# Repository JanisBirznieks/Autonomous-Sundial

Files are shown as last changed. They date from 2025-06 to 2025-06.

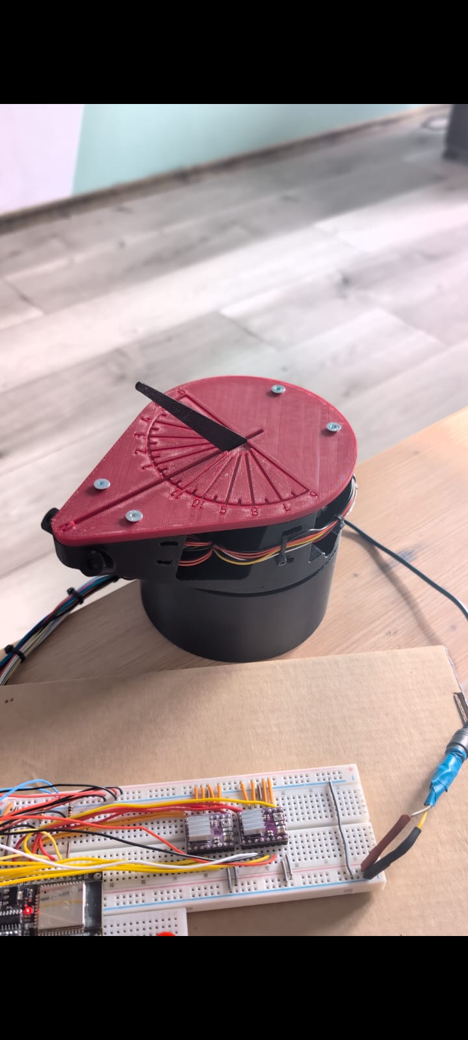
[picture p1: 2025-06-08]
Sundial.jpeg

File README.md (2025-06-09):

#  Autonomous Sundial

**Author:** Jānis Birznieks  
**Year:** 2025

This project is a physical, electromechanical sundial system that autonomously tracks the sun’s position to display accurate local solar time. It combines mechanical actuation, environmental sensing, and real-time data integration across three cooperating devices.

---

## 🔧 System Overview

The system runs across three hardware platforms, each with its own software component:

### 1. **ESP32 (Firmware: `main.cpp`)**
- Controls two stepper motors (azimuth + tilt)
- Reads sensor data (LDRs, AS5600 analog angle sensors, limit switches)
- Implements the full state machine (OFF, ON, PAUSED, RESET)  
- Executes sun-seeking and initialization subroutines

### 2. **Raspberry Pi (Script: `ESPSerialSender.py`)**
- Sends current time and location to the ESP32
- Reads serial telemetry from the ESP32
- Stores all received data in a local MySQL database

### 3. **Database/Visualization Machine (Script: `Sundial_Plots.py`)**
- Connects to the MySQL database
- Displays:
  - Polar chart for real-time azimuth
  - Polar chart for gnomon tilt
  - Smoothed time-series plots of LDR data
  - Live system state indicator

---

## 🧩 Included Components

| Type | File | Description |
|---|---|---|
| ESP32 Code  | `main.cpp` | Core firmware controlling motors, state logic, and sensors |
| Pi Script | `ESPSerialSender.py` | Syncs time/location and logs telemetry |
| Visualizer  | `Sundial_Plots.py` | Live data visualization from the MySQL database |

---

## 📄 License

This repository is distributed under a **custom Academic Use License**.

You are permitted to use, study, and modify this work **for non-commercial academic or research purposes only**. Commercial use is **strictly prohibited** without written permission from the author.

See [`LICENSE.txt`](LICENSE.txt) for full terms.

---

## 🛠️ Status

This is an academic project submitted as part of a final coursework requirement. The repository is currently **private** and shared for review purposes only.

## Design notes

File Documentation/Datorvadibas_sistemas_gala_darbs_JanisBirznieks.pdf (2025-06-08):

### RĪGAS TEHNISKĀ UNIVERSITĀTE

## Liepājas akadēmija

## Jānis Birznieks

## Mehatronika 3.kurss

## 191LMC006

# Autonomais saules pulkstenis

Students

Darba vadītājs

## Liepāja 2025

### Saturs

## Ievads

Saules pulksteņi ir vieni no senākajiem laika noteikšanas instrumentiem, kas darbojas, izmantojot Saules pozīciju un ēnas krišanas virzienu, lai norādītu aptuvenu diennakts laiku. Lai tie pareizi darbotos, saules pulkstenim jābūt orientētam pret īstajiem ziemeļiem, jo tieši no šīs puses tiek veikti ģeogrāfiskie novērojumi. Turklāt gnomona — ēnas metēja — leņķim jāatbilst lietotāja ģeogrāfiskajai platuma grādu vērtībai, lai ēna precīzi rādītu laiku.

Mūsdienās, kad pulksteņi un viedierīces ir plaši pieejamas un ļoti precīzas, saules pulksteņi vairāk tiek izmantoti kā dekoratīvi vai izglītojoši objekti. Tomēr šo klasisko laika noteikšanas principu var apvienot ar mūsdienu tehnoloģijām, radot automatizētu saules pulksteni, kas spēj patstāvīgi noteikt savu orientāciju un pielāgoties lietotāja atrašanās vietai.

Šī projekta mērķis ir izstrādāt ierīci, kura, izmantojot mikrodatoru un sensorus, automātiski noregulē savu pozīciju un gnomona leņķi, nodrošinot precīzu un ērtu laika nolasīšanu no saules pulksteņa neatkarīgi no tā, kur ierīce tiek novietota.

Projekts apvieno vairākas tehnoloģiskās jomas — mehānisko konstrukciju, sensoru datu apstrādi, mikrokontrolieru un mikrodatoru komunikāciju, kā arī algoritmu izstrādi. Lai gan šīs ierīces praktiskā nozīme mūsdienās ir ierobežota, projekts sniedz vērtīgu pieredzi inženiertehniskajā risinājumā, apgūstot sensoru integrāciju un automatizētu kontroli.

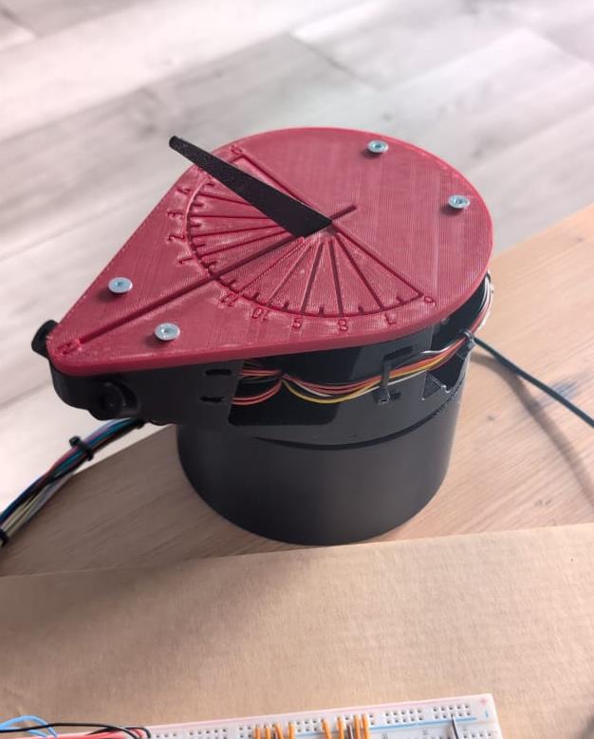
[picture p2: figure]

Attēls 1, Autonomā saules pulksteņa elektromehāniskais izpildījums

## Tēmas pamatojums

Šī projekta izvēle balstās uz vēlmi apvienot klasisku, analogā laikmeta tehnoloģiju – saules pulksteni – ar mūsdienu digitālajām iespējām, demonstrējot, kā tradicionālus mehānismus iespējams modernizēt ar mikroelektroniku, automatizāciju un sensoriem. Lai arī izveidotā ierīce būtībā atkārto funkciju, kuru mūsdienās veic jebkurš viedtālrunis vai pulkstenis, šī “tehnoloģiski pārsarežģītā” pieeja ļauj padziļināti izprast:

- analogā un digitālā signālu apstrādi;
- dažādu sensoru un aktuatoru pielietošanu;
- ģeogrāfisko koordinātu izmantošanu aprēķinos;
- mikrokontrolleru un mikrodatoru sadarbību;
- automatizētu mehānismu vadības algoritmu izstrādi.

Tēmas izvēle arī parāda, kā ar šķietami vienkāršu un “nepraktisku” ideju iespējams radīt daudzslāņainu projektu, kurā nepieciešama nopietna tehniskā plānošana un īstenošana. Šāda pieeja ne tikai ļauj demonstrēt dažādu jomu prasmes, bet arī motivē radošu pieeju inženiertehnisku risinājumu meklējumos.

## Prasību specifikācija

Funkcionālās prasības:

- Sistēmas ieejas (nolasāmie parametri):
- Lietotāja atrašanās vieta (platums un garums) – automātiski nolasīta (caur RasPi).
- Laiks – iegūts no Raspberry Pi (interneta sinhronizācija).
- Gaismas sensori – nosaka, no kurienes nāk spēcīgākais apgaismojums (analoga ievade).
- Enkoderi uz soļu motoriem – precīzai pozīcijas kontrolei un kļūdu korekcijai (ja gnomons vai pulkstenis kustības laikā tiek bloķēts).
- Divas pogas – ierīces ieslēgšana/izslēgšana, pauze vai attiestatīšana
- Aktuatora darbības atkarība no ievades:
- Soļu motori rotē platformu, lai to orientētu pret sauli, un pielāgo gnomona leņķi atkarībā no platuma.
- Sistēma automātiski aprēķina saules azimutu no laika un koordinātēm.
- Pozicionēšana tiek veikta, balstoties uz aprēķināto saules pozīciju, ar atsauci no enkoderiem.
- Datu apstrāde / pārsūtīšana / vizualizācija:
- ESP32 saņem datus no Raspberry Pi (laiks, atrašanās vieta).
- LED indikatori:
- Zaļais – sistēma ir iestatījusies.
- Dzeltenais - notiek sistēmas darbība,
- Sarkanais – sistēma izslēgta.
- ESP32 pārsūta aziumta leņķi, gaismas sensoru vērtības, platuma leņķi, sistēmas stāvokli uz Raspberry Pi, kas to tālāk nosūta uz lokālo datubāzi.
- Datubāzes iekārta veic datu vizualizāciju un apstrādi.
- Lietotāja saskarne:
- 2 pogas.
- 2 LED (zaļš un sarkans).

## Moduļu slēgums (komponentes)

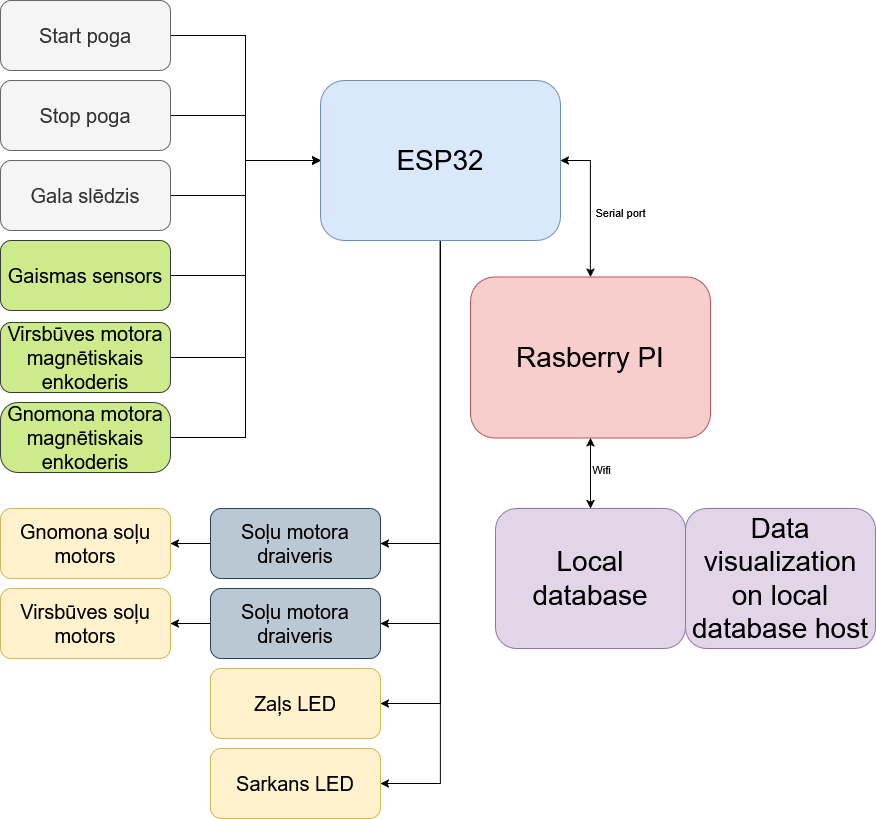
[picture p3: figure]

Attēls 2, Moduļu slēgums

Moduļu slēguma apraksts

Šajā sistēmā izmantota modulāra pieeja, kurā mikrokontrolleris ESP32 pārvalda sensorus, pogas, motorus un indikatorus, bet Raspberry Pi mikrodators reģistrē lokāciju un laika datus, kā arī pārsūta informāciju uz datubāzi.

ESP32 mezgls

ESP32 kalpo kā centrālais kontrolieris, kurš veic:

- Signālu nolasīšanu no ieejām:
- Start poga – aktivizē sistēmas ciklu.

- Stop poga – iedarbina pauzes vai izslēgšanas režīmu.
- Gala slēdzis – kalpo kā gnomona references punkts.
- Gaismas sensori (LDR) – noteic Saules virzienu.
- Magnetiskie enkoderi – reģistrē bāzes un gnomona motora pozīciju, izmantojot analogās vērtības no AS5600 sensoriem.
- Signālu nosūtīšanu uz izejām:
- Soļu motora draiveri – vadības signāli tiek sūtīti uz bāzes un gnomona motoriem (DRV8825), lai izpildītu kustības uz noteiktiem leņķiem.
- LED indikatori:

■ Zaļais LED - sistēma ir pabeigusi darbību.
■ Dzletenais LED - sistēma ir darbībā vai pauzē. ■ Sarkanais LED - sistēma ir izslēgta.

ESP32 arī veic aprēķinus, piemēram, pozicionēšanos pēc gaismas sensoriem un gnomona leņķa iestatīšanu pēc lietotāja koordinātām un laika.

Raspberry Pi mezgls

Raspberry Pi saņem seriālos datus no ESP32 caur serial port. Tas darbojas kā starpnieks starp ierīci un vietējo MySQL datubāzi – glabā datus par laiku, atrašanās vietu, Saules azimutu, sensoru mērījumiem, sistēmas stāvokli u.c. Datubāzes ierīcē notiek arī datu vizualizācijas – reāllaikā attēlo:

- Saules azimuta un gnomona leņķa polārās diagrammas,
- LDR vērtību vēsturi,
- sistēmas stāvokļa indikatoru.

## Principiālā shēma

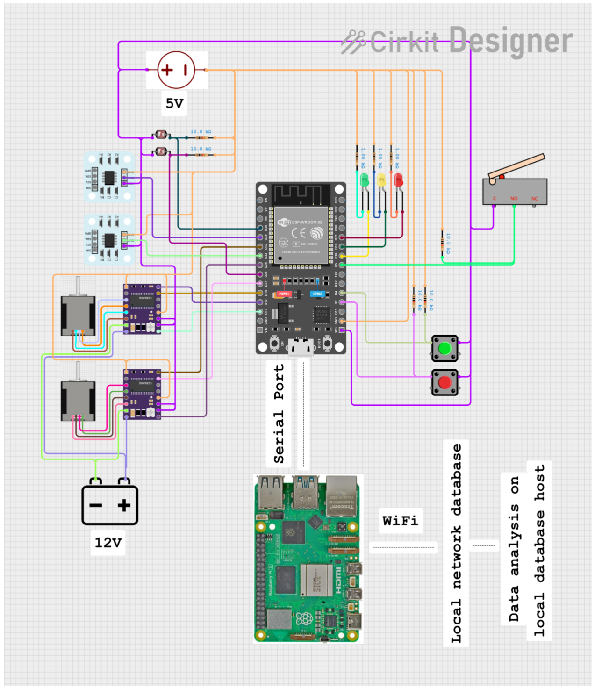
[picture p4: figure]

Attēls 3, Principiālā shēma

Komponente | Pins | Savienots ar
NEMA 17 | GREEN (A1) | DRV8825 A1
| BLUE (A2) | DRV8825 A2
| BLACK (B1) | DRV8825 B1
| RED (B2) | DRV8825 B2
NEMA 14 | RED (B2) | DRV8825 B2
| BLACK (B1) | DRV8825 B1
| GREEN (A1) | DRV8825 A1
| BLUE (A2) | DRV8825 A2
12V barošana | | DRV8825 VMOT, VMOT, GND
ESP32 | D14 | DRV8825 STEP
| D12 | DRV8825 DIR
| D13 | DRV8825 EN
| D27 | DRV8825 STEP
| D32 | DRV8825 DIR
| D25 | DRV8825 EN
Photocell (LDR1) | Pin 1 | Resistor, ESP32 D34
Photocell (LDR2) | Pin 1 | ESP32 D26
Galaslēdzis | NO | ESP32 D5
Pushbutton | Pin 1 | ESP32 D2
Pushbutton | Pin 1 | ESP32 D4
LED (green) | Anode | ESP32 D18
LED (yellow) | Anode | ESP32 D19
LED (red) | Anode | ESP32 D21
Tabula 1, Slēguma tabula

## Algoritms

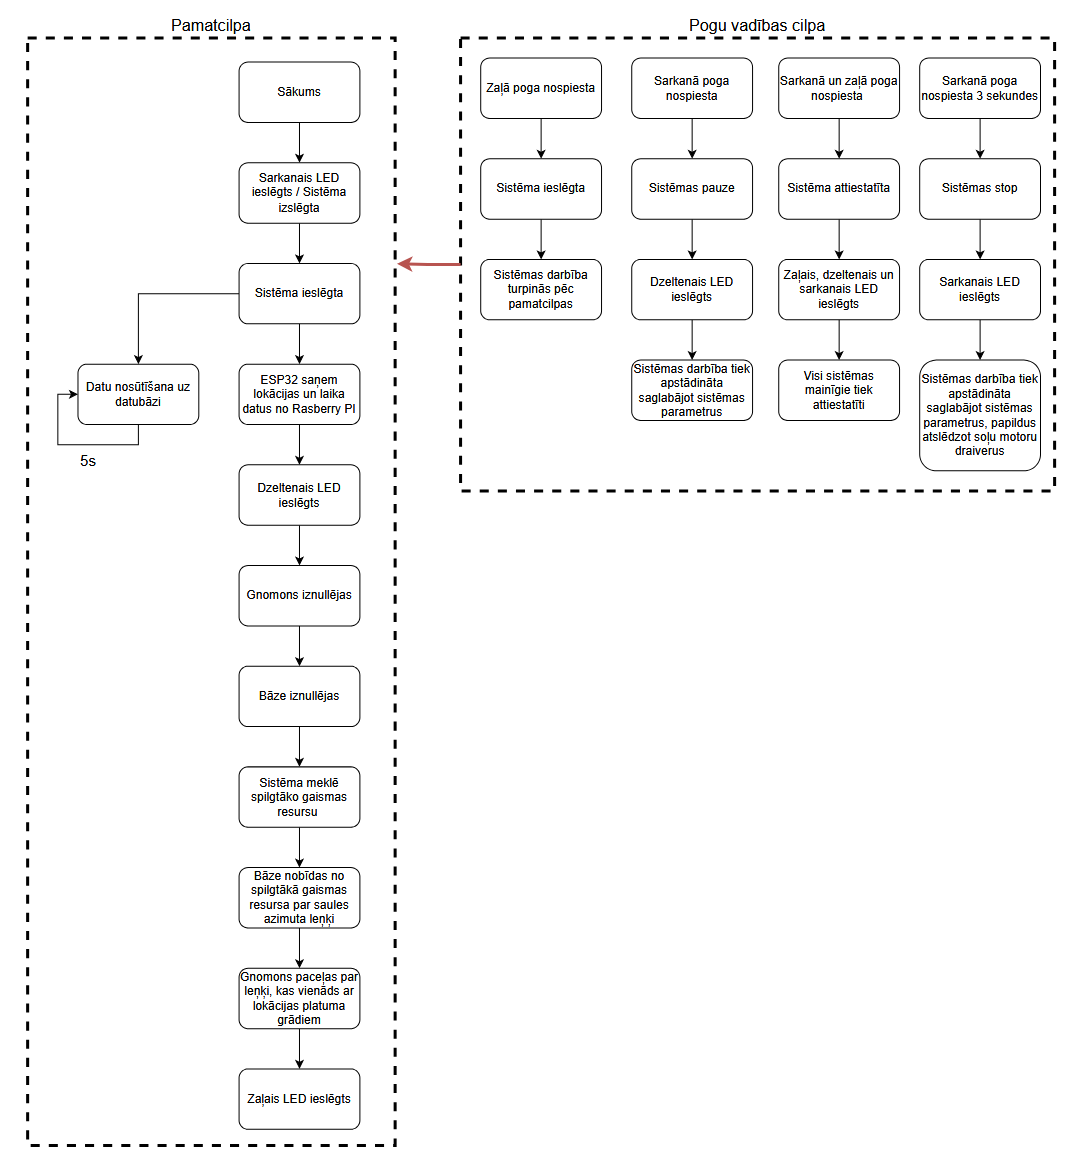
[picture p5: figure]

Attēls 4, Programmas algoritma blokshēma

## Galvenā cikla darbība

## Sistēmai pirmoreiz uzsākot darbu, tiek ieslēgts sarkans indikators, norādot, ka sistēma

ir izslēgta vai gaidstāvē. Kad lietotājs to ieslēdz, iedegas dzeltens LED, un sākas sistēmas

## darbības process . Vispirms ESP32 saņem reālā laika informāciju un atrašanās vietu no

Raspberry Pi (kas to attiecīgi ir saņēmis no interneta), un no šiem datiem aprēķina Saules azimuta leņķi.Tālāk gan bāze, gan gnomons tiek atgriezti sākuma pozīcijā.

## Kad tas paveikts, sistēma izmanto LDR (gaismas sensorus), lai atrastu spilgtāko gaismas avotu. Pēc tam, pamatojoties uz šo informāciju:

- Bāze tiek novirzīta par saules azimuta leņķi no spilgtākā gaismas avota.
- Gnomons paceļas atbilstoši lokācijas platuma grādiem.

## Sistēma aktivizē zaļo LED, kas norāda uz normālu darbību.Visu darbības laiku,ik pēc 5 sekundēm sistēma nosūta datus uz MySQL datubāzi, tai skaitā:

- laiku,
- aprēķināto Saules azimutu,
- LDR sensoru rādījumus,
- lokācijas platuma leņķi,
- sistēmas stāvokli.

## Pogu vadības apakšcikls

## Šis cikls darbojas neatkarīgi no galvenā cikla un ļauj lietotājam jebkurā brīdī mainīt sistēmas stāvokli:

- Sarkanā poga aktivizē pauzes režīmu, apstādinot motorus. Iedegas dzeltens LED.
- Zaļā poga atsāk darbību pēc pauzes.

## - Sarkanā + zaļā poga kopā izraisa atiestatīšanu – visi mainīgie tiek atgriezti sākotnējā

stāvoklī.

## - Sarkanā poga, turot to nospiestu 3 sekundes, izslēdz sistēmu, deaktivizē motoru

draiverus – aktivizējas sarkanais LED.

## Kods (apraksts)

Programmatūras sistēma ir paredzēta, lai fizikāli izkārtotu saules pulksteni atbilstoši saules pašreizējai pozīcijai, izmantojot reāllaika atrašanās vietas un laika datus. Sistēma sastāv no trim savstarpēji savienotām ierīcēm, kurās katrā darbojas specifiska programma:

- ESP32 — Autonomous Sundial (main.cpp): Vada aktuatorus, nolasa sensorus un izpilda visu saules pulksteņa mehānisko kustību.
- Raspberry Pi — ESPSerialSender.py : Iegūst ģeolokāciju un laiku no interneta, sazinās ar ESP32 un pārsūta sistēmas datus uz datubāzi.
- Datu bāzes ierīce — Sundial_Plots.py : Iegūst datus no MySQL datubāzes un vizualizē sistēmas statusu, sensoru rādījumus un saules orientāciju reāllaikā.

ESP32 — Autonomous Sundial (main.cpp)

Programmas mērķis

Šī programma darbojas uz ESP32 un veido sistēmas galveno vadības loģiku. Tās uzdevumi ir:

- Vadīt bāzes un gnomona motorus, izmantojot soļu motoru draiverus un analogo sensoru atgriezenisko saiti.
- Saņemt laiku un atrašanās vietas datus no Raspberry Pi.
- Aprēķināt saules pozīciju ar saules pozicionēšanas bibliotēku.
- Izmantot gaismas sensorus (LDR), lai nomērītu saules atrašanās pozīciju.
- Apstrādāt lietotāja ievadi caur pogām un norādīt sistēmas stāvokli ar LED indikatoriem.
- Nosūtīt sistēmas statusu un datus atpakaļ uz Raspberry Pi caur seriālo savienojumu.

Programma organizēta kā state machine, kas pārvalda sistēmas darbību (OFF, ON, PAUSED, RESET), un sub-state machine, kas veic saules pulksteņa uzstādīšanas un pozicionēšanas procedūru.

Galvenās apakšprogrammas un funkcijas

Zemāk aprakstīti katras funkcijas uzdevumi:

## 1. void resetMotorStates()

Atiestata visu motoru stāvokļu mainīgos. Izsaucas pēc sistēmas restartēšanas, lai motori sāktu no nulles pozīcijas.

## 2. bool trackLightSource(...)

LDR balstīta gaismas avota izsekošana:

- Salīdzina kreisās un labās LDR sensoru vērtības.
- Groza bāzes motoru, līdz sensori ir līdzsvaroti tolerances robežās.
- Ņem vērā spilgtāko gaismas avotu
Šis posms palīdz noteikt saules aptuveno pozīciju.

## 3. bool rotateMotorByOffset(...)

Groza motoru par relatīvu leņķi (piemēram, saules azimuta nobīdi):

- Nolasa pašreizējo pozīciju no AS5600 sensora.
- Aprēķina mērķa pozīciju kā: pašreizējā + nobīde.
- Kustība turpinās, līdz tiek sasniegta mērķpozīcija.

## 4. bool rotateMotorToPosition(...)

Groza motoru uz konkrētu absolūtu pozīciju:

- Līdzīga kā rotateMotorByOffset, bet ar fiksētu mērķi (piemēram, sākuma pozīciju).
- Lieto bāzes vai gnomona "nulēšanai".

## 5. void checkButtons()

Apstrādā pogu ievades, izmantojot Bounce2 bibliotēku:

- Zaļā + sarkanā poga → sistēmas RESET
- Zaļā poga → sistēma ON
- Sarkanā poga → sistēma PAUSED
- Sarkanās pogas turēšana 3 sekundes → sistēma OFF

## 6. void calculateSunAzimuth()

Aprēķina saules pašreizējo azimutu, izmantojot laiku un atrašanās vietu:

- Izmanto saules pozīciju bibliotēku.
- Leņķis pārveidots motoru mērogā (0–4096).

## 7. void parseSerialCommand(const String& input)

Apstrādā ienākošās seriālās komandas, kas atjauno sistēmas iekšējos mainīgos laika un vietas datiem.:

## - TIME:<hh>,<mm>,<ss>,<dd>,<mm>,<yyyy> - LOC:<platums>,<garums>

## 8. void receiveSerialData()

Nolasa seriālo buferi un nodo ievadītos datus parseSerialCommand funkcijai. Nodrošina, ka

ESP32 spēj saņemt Raspberry Pi sūtītos datus.

## 9. void sendSystemData()

Nosūta telemetrijas datus atpakaļ uz Raspberry Pi:

- Iekļauj: laika zīmogu, platumu, garumu, saules azimutu, LDR vērtības, bāzes leņķi, sistēmas stāvokli.

- Dati formatēti kā teksta rinda ar DATA: prefiksu.

Sistēmas inicializācija un galvenais cikls

## void setup()

Inicializē:

- Seriālo savienojumu
- Motora "enable" pinus
- Pogas un LED pinus
- Pogu atskaites laiku (debounce)
- Sākas SYSTEM_OFF stāvoklī.

## void loop()

Galvenā programma strukturēta ap stāvokļu mašīnu:

Sistēmas stāvokļi

1. SYSTEM_OFF
- Motori atspējoti.
- Iedegas sarkanais LED.
- Sistēma gaida.
2. SYSTEM_ON
Aktivizē apakšstāvokļu secību, lai sagatavotu un pozicionētu saules pulksteni: Apakšstāvokļi:
- STEP_ZERO_GNOMON: Gnomons tiek rotēts līdz mehāniskajai nulles pozīcijai

(izmantojot gala slēdzi).
- STEP_ZERO_BASE: Bāze tiek noregulēta uz fiksētu sākuma pozīciju (izmantojot

sensoru).
- SUN_TRACKING: Bāze tiek virzīta uz spožāko gaismas avotu (izmantojot LDR

sensorus).
- STEP_ROTATE_BASE: Bāze tiek rotēta atbilstoši saules azimuta aprēķinam.
- STEP_ROTATE_GNOMON: Gnomons tiek pacelts līdz vietējam platuma leņķim.
- STEP_DONE: Visi soļi pabeigti. Zaļais LED iedegas. Sistēma ir noregulēta.
3. SYSTEM_PAUSED
- Motori apstājas.
- Dzeltens LED iedegas.
4. SYSTEM_RESET
- Atiliek sistēmu uz sākuma stāvokli.
- Gaidīt laika un vietas datus.

Seriālā izvade

Cikla beigās ik pēc 5 sekundēm tiek izsaukta sendSystemData() funkcija, kas nosūta

aktuālos datus uz Raspberry Pi.

## Raspberry Pi — ESPSerialSender.py

Programmas mērķis

Šī Python programma darbojas uz Raspberry Pi un kalpo kā saziņas un datu apmaiņas tilts starp ESP32 un datubāzes serveri. Tās uzdevumi ir:

- Iegūt reāllaika laiku un atrašanās vietas datus no interneta, izmantojot iebūvēto sistēmas pulksteni un geocoder bibliotēku.
- Nosūtīt šo informāciju ESP32, lai tas spētu aprēķināt saules pozīciju.
- Saņemt sistēmas datus no ESP32 seriālajā formātā un saglabāt tos MySQL datubāzē.

Programma darbojas nepārtrauktā ciklā, regulāri atjauninot informāciju un uzraugot ESP32 izsūtītos datus.

Galvenās funkcijas

## send_time_and_location()

- Iegūst lokālo laiku.
- Mēģina noteikt ģeogrāfiskās koordinātas (platumu un garumu) ar IP balstītu geolokāciju.
- Ja tas neizdodas, izmanto rezerves vērtības.
- Nosūta datus uz ESP32 divās atsevišķās komandās: TIME: un LOC:.

## read_esp_data()

- Klausās seriālajā portā.
- Ja saņemta rinda, kas sākas ar DATA:, tā tiek parsēta 8 laukos:
- Laika zīmogs
- Platums
- Garums
- Saules azimuts
- LDR kreisais sensors
- LDR labais sensors
- Bāzes pozīcija
- Sistēmas stāvoklis
- Pēc veiksmīgas parsēšanas dati tiek ierakstīti MySQL datubāzē ar
insert_data_to_mysql(...).

## insert_data_to_mysql(...)

- Veic SQL INSERT vaicājumu tabulā sun_tracking_data, saglabājot visu ienākošo

telemetriju strukturētā veidā.

Galvenais cikls

Programma darbojas bezgalīgā while True ciklā:

- Ik pēc 5 sekundēm tiek izsaukta send_time_and_location(), lai nodrošinātu ESP32

ar aktuāliem datiem.
- Nepārtraukti tiek klausīts ESP32 seriālais izvads, un saņemtie dati tiek apstrādāti.
- Starp cikliem programma īslaicīgi "guļ", lai mazinātu CPU noslodzi (sleep(0.9)).

Kopsavilkums

Šī programma ir vienkārša, bet būtiska — tā sinhronizē ESP32 ar reālo pasauli (laiku un atrašanās vietu) un nodrošina telemetrijas plūsmu uz datubāzi.

Datu bāzes ierīce — Sundial_Plots.py

Programmas mērķis

Šī Python programma darbojas uz vietējās datubāzes ierīces un nodrošina reāllaika vizualizāciju par saules pulksteņa sistēmas darbību. Tās uzdevumi ir:

- Savienoties ar MySQL datubāzi un nolasīt jaunākos telemetrijas ierakstus.
- Attēlot datus vizuāli, izmantojot matplotlib, sniedzot lietotājam skaidru priekšstatu par

sistēmas stāvokli, saules pozīciju, sensoru rādījumiem u.c.
- Atjaunot grafikus ik pēc 5 sekundēm

Vizualizācijas paneļi

Programma izveido četrus galvenos skatījumus (subplot) vienā logā:

### 1. Saules azimuts (polārais grafiks)

- Attēlo saules virzienu uz kompasa diska.
- 0° = Ziemeļi; grafiks orientēts ar pulksteņrādītāja virzienu.
- Dati tiek iegūti no pēdējā sun_azimuth ieraksta datubāzē.

### 2. Gnomona slīpums (polārais grafiks)

- Attēlo platuma leņķi lietotāja lokācijā.

### 3. LDR sensoru vērtības (līniju grafiks)

- Attēlo kreisā un labā LDR sensora vērtības laika gaitā.
- Dati tiek izlīdzināti ar vienkāršu delta koeficientu (SMOOTHING_DELTA), lai iegūtu

gludāku līkni.
- Rāda līdz 100 pēdējiem punktiem (MAX_POINTS).

### 4. Sistēmas stāvoklis (teksta logs)

- Vizualizē, kādā stāvoklī šobrīd atrodas sistēma (piemēram, SYSTEM_ON, SYSTEM_PAUSED,

utt.).
- Teksts centrēts, ar palielinātu fontu ērtai nolasīšanai.

Datu iegūšana

## fetch_latest_data()

- Veic SQL pieprasījumu uz sun_tracking_data tabulu.
- Iegūst jaunākos ierakstus (pēc timestamp), apgriež to kārtību hronoloģiskai attēlošanai.
- Atgriež rezultātus kā sarakstu ar vārdotiem lauciņiem (dictionary=True).

Grafiku atjaunošana

## update_plot(frame)

- Tiek izsaukta ik sekundi, izmantojot matplotlib.animation.FuncAnimation.
- Atjauno visus četrus vizualizācijas paneļus ar jaunākajiem datiem no datubāzes.
- Veic LDR datu izlīdzināšanu, pārkonvertē leņķus uz radiāniem polārajiem grafikiem.

Kopsavilkums

Sundial_Plots.py ir lietotāja interfeiss sistēmas uzraudzībai. Tas piedāvā vizuālu un intuitīvu skatījumu uz sensoriem, mehānismiem un saules pozīciju, un ļauj nekavējoties redzēt, kā sistēma reaģē uz vidi un ievaddatiem.

Koda pielikumu saraksts:

- Pielikums A – main.pdf (css)
ESP32 mikrokontrollera programma: Autonomous Sundial
- Pielikums B – ESPSerialSender.pdf (py)
Raspberry Pi skripts: laika/atrašanās vietas sinhronizācija un datu uzglabāšana
- Pielikums C – Sundial_Plots.pdf (py)
Vizualizācijas rīks, kas lasa no MySQL datubāzes un attēlo datus reāllaikā

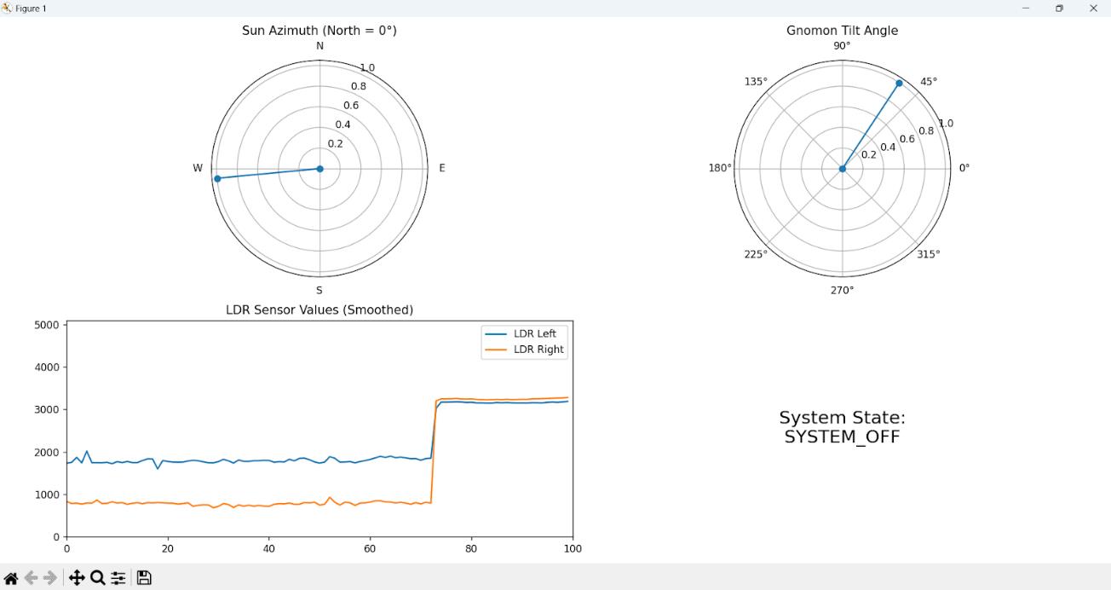
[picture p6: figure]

Attēls 5, Vizualizācija Sundial_plots.py

## Testēšana

Nr. | Testēšanas elements | Testēšanas mērķis | Rezultāts
1 | Sistēmas barošana | Pārbaudīt, vai ESP32 un visi komponenti saņem atbilstošu barošanu | Sistēma ieslēdzas pareizi un LED indikatori darbojas
2 | Stepper draivera strāvas iestatījums | Optimizēt motora strāvu, lai novērstu pārkaršanu vai zemu griezes momentu | Iestatīts uz 0.3 V ref, motors darbojas stabili
3 | Pogas (Start, Stop, Reset, Emergency) | Pārbaudīt pogu darbību un sistēmas reakciju uz tām | Sistēma korekti pārslēdz stāvokļus, Emergency aptur visu darbību
4 | Limit switch | Pārbaudīt nulles pozīcijas noteikšanu un aizsardzību | Limit switch nostrādā un sistēma korekti nolasa pozīciju
5 | Gnomona motors | Pārbaudīt motora darbību un virziena kontroli | Motors kustas pareizi un tiek kontrolēts caur stepper draiveri
6 | Bāzes motors | Pārbaudīt rotācijas kustību un pozicionēšanu | Motors rotē 360°, tiek veikta korekta pozicionēšana
7 | AS5600 sensori | Pārbaudīt sensora datus un to reakciju uz kustību | Abi sensori strādā bez problēmām
8 | LDR sensori | Pārbaudīt saules gaismas intensitātes nolasīšanu un reakciju uz to | Viens LDR bojāts — nomainīts; pēc tam abi darbojas korekti
9 | Gaismas izsekošanas algoritms | Pārbaudīt, vai tiek izsekots pareizais gaismas avots | Sākotnēji izsekoja nepareizus avotus; tika ieviests algoritms ar spilgtuma pārbaudi un ilguma filtru
10 | Motora vadības algoritmu testēšana | Pārbaudīt, vai kustības tiek pareizi aprēķinātas un veiktas (stepper vadība, leņķu kompensācija, nulles pozīcija) | Motori kustas paredzētajā virzienā un ātrumā, tiek ievērota tolerances zona un tiek veikta korekta pozicionēšana
11 | Datu nosūtīšana uz Raspberry Pi | Pārbaudīt, vai ESP32 pareizi nosūta telemetrijas datus uz RPi | Seriālā komunikācija strādā, dati tiek nosūtīti ik sekundi
12 | SQL datubāze | Pārbaudīt, vai dati tiek ierakstīti datubāzē | Veiksmīgi tiek glabāti dati par pozīcijām, gaismas intensitāti, sistēmas statusu
13 | Datu vizualizācija Python | Reālā laikā attēlot azimutu, lokācijas platuma leņķi, LDR vērtības un sistēmas statusu | Grafiki tiek atjaunoti ik sekundi, rādījumi ir vizuāli korekti
14 | Gaismas avota simulācija ar datora ekrānu | Sākotnējā testēšana bez RS-35 luktura | Sistēma reaģēja uz ekrāna gaismu, bet netika sasniegta pietiekama spilgtuma uzticamība
15 | Mehāniskā bāzes savienojuma izturība | Pārbaudīt, vai motors reāli pagriež pulksteni | Bāzes savienojums sākumā slīdēja; tika nostiprināts mehāniski ar līmi
16 | Sistēmas gala testēšana | Pārbaudīt visu sistēmu kā vienotu bloku – no datu saņemšanas līdz vizualizācijai un reakcijai uz gaismu | Sistēma darbojas kā paredzēts, tiek veikta sinhrona datu apmaiņa, kustības, vizualizācija un datu uzglabāšana

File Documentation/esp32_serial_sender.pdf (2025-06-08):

send_to_esp32.py

### 1 import mysql.connector 2 import serial 3 import time 4 import geocoder 5 from datetime import datetime, timedelta

6
7 # Serial connection

### 8 ser = serial.Serial('COM6', 115200, timeout=1) 9 time.sleep(2) # Wait for ESP32 to initialize

10
11 # MySQL connection setup

### 12 db = mysql.connector.connect(

13 host="localhost",
14 user="esp_user",
15 password="ESPtesting123!!!",

### 16 database="esp_user"

17 )

### 18 cursor = db.cursor()

19

### 20 def send_time_and_location(): 21 offset = timedelta(hours=3) 22 now = datetime.utcnow() + offset

23 time_string = f"TIME:{now.hour},{now.minute},{now.second},{now.day},{now.month}, {now.year}\n"
24

### 25 g = geocoder.ip('me') 26 if g.ok and g.latlng: 27 latitude, longitude = g.latlng 28 else: 29 latitude, longitude = 56.5047, 21.0108 # Fallback if geolocation fails

30 | print(" | Using fallback coordinates.")
31

### 32 location_string = f"LOC:{latitude},{longitude}\n"

33

### 34 print("Sending to ESP32:") 35 print(" Time:", time_string.strip()) 36 print(" Location:", location_string.strip())

37

### 38 ser.write(time_string.encode()) 39 time.sleep(0.1) 40 ser.write(location_string.encode())

41

### 42 print(" Status: Sent\n")

43
44 def insert_data_to_mysql(timestamp, latitude, longitude, azimuth, ldr_left, ldr_right,
| base_pos, state):

### 45 query = """ 46 INSERT INTO sun_tracking_data (

47 timestamp, latitude, longitude, sun_azimuth,

### 48 ldr_left, ldr_right, base_position, system_state

49 ) VALUES (%s, %s, %s, %s, %s, %s, %s, %s)

50 """
51 values = (timestamp, latitude, longitude, azimuth, ldr_left, ldr_right, base_pos, state)

### 52 cursor.execute(query, values) 53 db.commit()

54

55 def read_esp_data(): 56 while ser.in_waiting: 57 line = ser.readline().decode().strip() 58 if line.startswith("DATA:"): 59 data = line[len("DATA:"):] 60 print("[ESP DATA]", data) 61 parts = data.split(',') 62 if len(parts) == 8: 63 timestamp, lat, lon, az, ldr_l, ldr_r, base, state = parts 64 try:

65 insert_data_to_mysql(timestamp, float(lat), float(lon), float(az),

### 66 int(ldr_l), int(ldr_r), int(base), state) 67 except Exception as e: 68 print("Error inserting to DB:", e)

69
70 # === Main loop ===

### 71 last_sent = time.time()

72

### 73 while True: 74 now = time.time()

75
76 # Send time/location update every 5 seconds

### 77 if now - last_sent >= 5: 78 send_time_and_location() 79 last_sent = now

80
81 # Always listen for ESP responses

### 82 read_esp_data()

83

### 84 time.sleep(0.9)

85

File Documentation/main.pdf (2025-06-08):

src\main.cpp

1 #include <Arduino.h>
2 #include <AccelStepper.h> 3 #include <Bounce2.h>
4 #include <SolarCalculator.h> 5 #include <TimeLib.h>
6
7 // === Pin Definitions ===
8
9 // Gnomon motor (Motor 2)
10 | #define GNOMON_STEP_PIN 27 | // DRV8825 STEP (Gnomon motor)
11 | #define GNOMON_DIR_PIN 32 | // DRV8825 DIR (Gnomon motor)
12 | #define GNOMON_EN_PIN 25 | // DRV8825 EN (Gnomon motor)
13 AccelStepper gnomonMotor(AccelStepper::DRIVER, GNOMON_STEP_PIN, GNOMON_DIR_PIN); 14 int gnomonZeroPosition = 0;
15
16 // Base motor (Motor 1)
17 | #define BASE_STEP_PIN 14 | // DRV8825 STEP (Base motor)
18 | #define BASE_DIR_PIN 12 | // DRV8825 DIR (Base motor)
19 | #define BASE_EN_PIN 13 | // DRV8825 EN (Base motor)
20 AccelStepper baseMotor(AccelStepper::DRIVER, BASE_STEP_PIN, BASE_DIR_PIN); 21
22 // Light Dependent Resistors (LDR)
23 | #define LDR_RIGHT_PIN 34 | // Photocell (LDR) right side
24 | #define LDR_LEFT_PIN 26 | // Photocell (LDR) left side
25
26 // Limit switch
27 | #define LIMIT_SWITCH_PIN 5 | // Limit switch (Normally Open)
28
29 // LEDs
30 | #define LED_GREEN_PIN 18 | // Green LED (anode)
31 | #define LED_YELLOW_PIN 19 | // Yellow LED (anode)
32 | #define LED_RED_PIN 21 | // Red LED (anode)
33
34 // Pushbuttons
35 | #define BUTTON_GREEN_PIN 4 | // Green pushbutton
36 | #define BUTTON_RED_PIN 2 | // Red pushbutton
37
38 Bounce greenButton = Bounce();
39 Bounce redButton = Bounce();
40
41 //Sun position values
42 | double latitude = 56.5047; | // Your latitude
43 | double longitude = 21.0108; | // Your longitude
44 | int utc_offset = 3; | // Local time zone offset
45
46 // Set manually:
47 int setHour = 5;
48 int setMinute = 50;
49 int setSecond = 0;
50 int setDay = 1;

51 int setMonth = 6;
52 int setYear = 2025;
53
54 double sunAzimuth = 0.0; 55 int azimuthTarget = 0;
56
57 //Serial send delay
58 unsigned long lastDataSendTime = 0;

### 59 const unsigned long dataSendInterval = 1000; // send every 1000 ms = 1 second

60
61 //Serial communication data
62 bool timeReceived = false;
63 bool locationReceived = false; 64
65 //Serial Commands
66 /*
67

### 68 TIME:12,0,0,1,6,2025 69 LOC:56.946,24.105

70 */
71
72 // System states

### 73 enum SystemState {

74 SYSTEM_OFF,
75 SYSTEM_ON,
76 SYSTEM_PAUSED,

### 77 SYSTEM_RESET

78 };
79
80 SystemState currentState = SYSTEM_OFF; 81
82 //Subsstates

### 83 enum SystemSubState {

84 STEP_ZERO_GNOMON,
85 STEP_ZERO_BASE,
86 SUN_TRACKING,
87 STEP_ROTATE_BASE,
88 STEP_ROTATE_GNOMON,

### 89 STEP_DONE

90 };
91
92 SystemSubState subState = STEP_ZERO_GNOMON;
93
94 // AS5600 Analog Outputs
95 #define AS5600_GNOMON_PIN 33 // Gnomon AS5600 analog out
96 | #define AS5600_BASE_PIN 35 | // Base AS5600 analog out

### 97 const int BASE_SENSOR_OFFSET = -120; // Opposite of 2700 on a 12-bit scale

98
99 // Solar positioning values
100 int SunOffsetAmount = round(90 * (4096.0 / 360.0)); // Sun axiom Offset angle 101 int gnomonOffsetAmount = (round(-(latitude-11.77)) * (4096.0 / 360.0)); // Gnomon
| Offset angle
102 int gnomonZeroTarget = round(-220 * (4096.0 / 360.0)); // Gnomon Zero target angle

103 const int baseZeroTarget = 2150; // or whatever value you consider zero 104
105 int readBaseSensorOffset() {
106 int raw = analogRead(AS5600_BASE_PIN);
107 return (raw + BASE_SENSOR_OFFSET + 4096) % 4096; 108 }
109
110 struct MotorRotationState {
111 bool started = false;
112 bool complete = false; 113 int startingPosition = 0;
114 };
115
116 MotorRotationState baseOffsetState; 117 MotorRotationState gnomonOffsetState; 118 MotorRotationState gnomonTargetState; 119 MotorRotationState baseZeroState; 120 MotorRotationState baseTrackingState; 121
122 void resetMotorStates() {
123 baseOffsetState.started = false; 124 baseOffsetState.complete = false; 125
126 gnomonOffsetState.started = false; 127 gnomonOffsetState.complete = false; 128
129 gnomonTargetState.started = false; 130 gnomonTargetState.complete = false; 131
132 baseZeroState.started = false; 133 baseZeroState.complete = false; 134
135 baseTrackingState.started = false; 136 baseTrackingState.complete = false;
137 }
138
139 bool trackLightSource(AccelStepper &motor, int ldrLeftPin, int ldrRightPin, MotorRotationState &state) {
140 const int tolerance = 5;
141 const int minBrightness = 2000;
142 const float brightnessThresholdRatio = 0.8; 143 static int maxBrightnessSeen = 0;
144 static unsigned long lastMaxUpdate = 0; 145
146 if (state.complete) return true;
147
148 if (!state.started) {
149 motor.setMaxSpeed(200);
150 state.started = true;
151 Serial.println("Light tracking started..."); 152 }
153
154 int leftValue = analogRead(ldrLeftPin);

155 int rightValue = analogRead(ldrRightPin); 156 int maxCurrent = (leftValue + rightValue)/2;
157
158 // Update peak brightness
159 if (millis() - lastMaxUpdate > 60000 || maxCurrent > maxBrightnessSeen) { 160 maxBrightnessSeen = maxCurrent;
161 lastMaxUpdate = millis();
162 }
163
164 int brightnessThreshold = brightnessThresholdRatio * maxBrightnessSeen; 165
166 Serial.print("LDR Left: ");
167 Serial.print(leftValue);
168 Serial.print(" | LDR Right: ");
169 Serial.print(rightValue);
170 Serial.print(" | Max seen: ");
171 Serial.print(maxBrightnessSeen);
172 Serial.print(" | Required: ");
173 Serial.println(brightnessThreshold); 174
175 int difference = leftValue - rightValue; 176
177 // Check if aligned and bright enough 178 if (
179 abs(difference) <= tolerance && 180 leftValue >= minBrightness &&
181 rightValue >= minBrightness && 182 maxCurrent >= brightnessThreshold 183 ) {
184 motor.stop();
185 state.complete = true;
186 delay(2000);
187 Serial.println("Light tracking complete."); 188 return true;
189 }
190
191 // Keep moving toward brighter side
192 motor.setSpeed(difference > 0 ? -50 : 50); 193 motor.runSpeed();
194 return false;
195 }
196
197 bool rotateMotorByOffset(AccelStepper &motor, int sensorPin,int offsetAngle, MotorRotationState &state, int maxSpeed = 200, int moveSpeed = 100, int tolerance = 2) {
198 if (state.complete) return true;
199
200 if (!state.started) {
201 motor.setMaxSpeed(maxSpeed);
202 state.startingPosition = analogRead(sensorPin); 203 state.started = true;
204
205 Serial.print("Starting position: ");

206 Serial.println(state.startingPosition);
207 Serial.println("Rotating motor by offset..."); 208 }
209
210 int currentPosition = analogRead(sensorPin);
211 int targetPosition = (state.startingPosition + offsetAngle + 4096) % 4096; 212
213 int difference = (targetPosition - currentPosition + 4096) % 4096;
214 if (difference > 2048) difference -= 4096;
215
216 Serial.print("Current: ");
217 Serial.print(currentPosition);
218 Serial.print(" | Target: ");
219 Serial.print(targetPosition);
220 Serial.print(" | Diff: ");
221 Serial.println(difference);
222
223 if (abs(difference) <= tolerance) {
224 motor.stop();
225 state.complete = true;
226 Serial.println("Offset rotation complete."); 227 return true;
228 }
229
230 motor.setSpeed(difference > 0 ? -moveSpeed : moveSpeed); 231 motor.runSpeed();
232 return false;
233 }
234
235 bool rotateMotorToPosition(AccelStepper &motor, int sensorPin, int targetPosition, MotorRotationState &state) {
236 const int tolerance = 2;
237
238 if (state.complete) return true; 239
240 if (!state.started) {
241 motor.setMaxSpeed(200);
242 state.started = true;
243 Serial.print("Target Position: "); 244 Serial.println(targetPosition);
245 }
246
247 int currentPosition = analogRead(sensorPin);
248 int difference = (targetPosition - currentPosition + 4096) % 4096; 249 if (difference > 2048) difference -= 4096;
250
251 Serial.print("Current: ");
252 Serial.print(currentPosition);
253 Serial.print(" | Target: ");
254 Serial.print(targetPosition);
255 Serial.print(" | Diff: ");
256 Serial.println(difference); 257

258 if (abs(difference) <= tolerance) {
259 motor.stop();
260 state.complete = true;
261 Serial.println("Motor reached target position."); 262 return true;
263 }
264
265 motor.setSpeed(difference > 0 ? -100 : 100); 266 motor.runSpeed();
267 return false;
268 }
269
270 void checkButtons() {
271 greenButton.update();
272 redButton.update();
273
274 static unsigned long redPressStart = 0;
275 static bool redHoldChecked = false;
276
277 bool greenPressed = greenButton.read() == HIGH; 278 bool redPressed = redButton.read() == HIGH; 279
280 // Handle both buttons for system reset
281 if (greenPressed && redPressed) {
282 currentState = SYSTEM_RESET;
283 Serial.println("System RESET");
284 digitalWrite(LED_GREEN_PIN, HIGH); 285 digitalWrite(LED_YELLOW_PIN, HIGH); 286 digitalWrite(LED_RED_PIN, HIGH); 287 return;
288 }
289
290 // Green button press
291 if (greenButton.rose() && !redPressed) { 292 currentState = SYSTEM_ON;
293 Serial.println("System ON");
294 }
295
296 // Red button press
297 if (redButton.rose()) {
298 currentState = SYSTEM_PAUSED; 299 redPressStart = millis();
300 redHoldChecked = false;
301 Serial.println("System PAUSED");
302 }
303
304 // Check if red has been held for 3 seconds
305 if (redPressed && currentState == SYSTEM_PAUSED && !redHoldChecked) { 306 if (millis() - redPressStart >= 3000) {
307 currentState = SYSTEM_OFF;
308 redHoldChecked = true;
309 Serial.println("System OFF (long hold)"); 310 }

311 }
312
313 // Reset the flag if red is released 314 if (redButton.rose()) {
315 redHoldChecked = false;
316 }
317 }
318
319 void calculateSunAzimuth() {
320 // Set system time
321 setTime(setHour, setMinute, setSecond, setDay, setMonth, setYear); 322 time_t utc = now();
323
324 double elevation;
325 calcHorizontalCoordinates(utc, (round(-(latitude-11.77)) * (4096.0 / 360.0)), longitude, sunAzimuth, elevation);
326
327 Serial.print("Sun Azimuth: ");
328 Serial.print(sunAzimuth);
329 Serial.println("°");
330
331 // Convert to sensor units (0–4096)
332 azimuthTarget = round((sunAzimuth / 360.0) * 4096.0); 333 Serial.print("Sensor units: ");
334 Serial.println(azimuthTarget);
335 }
336
337 void parseSerialCommand(const String& input) {
338 if (input.startsWith("TIME:")) {
339 sscanf(input.c_str(), "TIME:%d,%d,%d,%d,%d,%d",
340 &setHour, &setMinute, &setSecond, &setDay, &setMonth, &setYear); 341
342 timeReceived = true;
343 Serial.println("Time variables updated.");
344 }
345 else if (input.startsWith("LOC:")) {
346 sscanf(input.c_str(), "LOC:%lf,%lf", &latitude, &longitude); 347 locationReceived = true;
348 Serial.println("Location variables updated.");
349 }
350 else {
351 Serial.println("Unknown command.");
352 }
353 }
354
355 void receiveSerialData() {
356 static String inputBuffer = ""; 357
358 while (Serial.available()) { 359 char c = Serial.read();
360
361 if (c == '\n') {
362 // Process complete input line

363 parseSerialCommand(inputBuffer); 364 inputBuffer = "";
365 } else {
366 inputBuffer += c;
367 }
368 }
369 }
370
371 void sendSystemData() {
372 // Get current time from TimeLib
373 char nowTimestamp[20];
374 snprintf(nowTimestamp, sizeof(nowTimestamp), "%04d-%02d-%02d %02d:%02d:%02d", 375 year(), month(), day(), hour(), minute(), second());
376
377 time_t utc = now();
378 double elevation;
379 calcHorizontalCoordinates(utc, round(-(latitude-11.77) * (4096.0 / 360.0)), longitude, sunAzimuth, elevation);
380
381 // Begin with identifiable prefix
382 Serial.print("DATA:");
383
384 // Send CSV-formatted line over Serial
385 Serial.print(nowTimestamp); Serial.print(","); 386 Serial.print(latitude); Serial.print(",");
387 Serial.print(longitude); Serial.print(",");
388 Serial.print(sunAzimuth); Serial.print(",");
389 Serial.print(analogRead(LDR_LEFT_PIN)); Serial.print(","); 390 Serial.print(analogRead(LDR_RIGHT_PIN)); Serial.print(","); 391 Serial.print(readBaseSensorOffset()); Serial.print(","); 392
393 // Send system state as a string
394 switch (currentState) {
395 | case SYSTEM_OFF: | Serial.println("SYSTEM_OFF"); break;
396 | case SYSTEM_ON: | Serial.println("SYSTEM_ON"); break;
397 case SYSTEM_PAUSED: Serial.println("SYSTEM_PAUSED"); break; 398 case SYSTEM_RESET: Serial.println("SYSTEM_RESET"); break; 399 }
400 }
401
402 // === Setup ===
403 void setup() {
404 Serial.begin(115200);
405
406 // Initialize LED pins
407 pinMode(LED_GREEN_PIN, OUTPUT); 408 pinMode(LED_YELLOW_PIN, OUTPUT);
409 pinMode(LED_RED_PIN, OUTPUT);
410
411 // Example: Turn all LEDs off at startup 412 digitalWrite(LED_GREEN_PIN, LOW);
413 digitalWrite(LED_YELLOW_PIN, LOW);
414 digitalWrite(LED_RED_PIN, LOW);

415
416 pinMode(GNOMON_EN_PIN, OUTPUT); 417 pinMode(BASE_EN_PIN, OUTPUT);
418
419 //Attach buttons
420 greenButton.attach(BUTTON_GREEN_PIN, INPUT); 421 redButton.attach(BUTTON_RED_PIN, INPUT);
422
423 // Set debounce interval
424 greenButton.interval(10); // or whatever fits your physical setup 425 redButton.interval(10);
426 Serial.println("System OFF");
427
428 }
429
430 // === Loop ===
431 void loop() {
432 checkButtons();
433 switch (currentState) {
434 case SYSTEM_OFF:
435 digitalWrite(GNOMON_EN_PIN, HIGH); // Enable gnomon driver
436 | digitalWrite(BASE_EN_PIN, HIGH); | // Enable base driver
437 digitalWrite(LED_GREEN_PIN, LOW);
438 digitalWrite(LED_YELLOW_PIN, LOW);
439 digitalWrite(LED_RED_PIN, HIGH);
440 break;
441
442 case SYSTEM_ON:
443 if (!timeReceived || !locationReceived) {
444 receiveSerialData();
445 Serial.println("Waiting for TIME and LOCATION data..."); 446 delay(1000);
447 break;
448 }
449 digitalWrite(GNOMON_EN_PIN, LOW); // Enable gnomon driver
450 | digitalWrite(BASE_EN_PIN, LOW); | // Enable base driver
451 switch (subState) {
452 case STEP_ZERO_GNOMON:
453
454 digitalWrite(LED_GREEN_PIN, LOW);
455 digitalWrite(LED_YELLOW_PIN, HIGH);
456 digitalWrite(LED_RED_PIN, LOW);
457 rotateMotorByOffset(gnomonMotor, AS5600_GNOMON_PIN, gnomonZeroTarget,
| gnomonTargetState);
458 if ((digitalRead(LIMIT_SWITCH_PIN) == HIGH)) {
459 calculateSunAzimuth();
460 subState = STEP_ZERO_BASE;
461 }
462 break;
463
464 case STEP_ZERO_BASE:
465 digitalWrite(LED_GREEN_PIN, LOW); 466 digitalWrite(LED_YELLOW_PIN, HIGH);

467 digitalWrite(LED_RED_PIN, LOW);
468 if (rotateMotorToPosition(baseMotor, AS5600_BASE_PIN, baseZeroTarget, baseZeroState)) {
469 delay(1000);
470 subState = SUN_TRACKING;
471 }
472 break;
473
474 case SUN_TRACKING:
475 digitalWrite(LED_GREEN_PIN, LOW);
476 digitalWrite(LED_YELLOW_PIN, HIGH);
477 digitalWrite(LED_RED_PIN, LOW);
478 if (trackLightSource(baseMotor, LDR_LEFT_PIN, LDR_RIGHT_PIN, baseTrackingState)) {
479 subState = STEP_ROTATE_BASE; // Or whatever comes next 480 }
481 break;
482
483 case STEP_ROTATE_BASE:
484 digitalWrite(LED_GREEN_PIN, LOW);
485 digitalWrite(LED_YELLOW_PIN, HIGH);
486 digitalWrite(LED_RED_PIN, LOW);
487 if (rotateMotorByOffset(baseMotor, AS5600_BASE_PIN, azimuthTarget, baseOffsetState)) {
488 subState = STEP_ROTATE_GNOMON;
489 }
490 break;
491
492 case STEP_ROTATE_GNOMON:
493 digitalWrite(LED_GREEN_PIN, LOW);
494 digitalWrite(LED_YELLOW_PIN, HIGH);
495 digitalWrite(LED_RED_PIN, LOW);
496 if (rotateMotorByOffset(gnomonMotor, AS5600_GNOMON_PIN, gnomonOffsetAmount, gnomonOffsetState)) {
497 subState = STEP_DONE;
498 }
499 break;
500
501 case STEP_DONE:
502 // System is now fully set up 503 digitalWrite(LED_GREEN_PIN, HIGH);
504 digitalWrite(LED_YELLOW_PIN, LOW);
505 digitalWrite(LED_RED_PIN, LOW);
506 Serial.println("All system tasks complete."); 507 break;
508 }
509 break;
510
511 case SYSTEM_PAUSED:
512 digitalWrite(LED_GREEN_PIN, LOW); 513 digitalWrite(LED_YELLOW_PIN, HIGH); 514 digitalWrite(LED_RED_PIN, LOW); 515 break;

516
517 case SYSTEM_RESET:
518 // Reset everything
519 resetMotorStates();
520 timeReceived = false;
521 locationReceived = false; 522 subState = STEP_ZERO_GNOMON;
523 break;
524 }
525 if (millis() - lastDataSendTime >= dataSendInterval) { 526 lastDataSendTime = millis();
527 sendSystemData();
528 }
529 }
530
531
532

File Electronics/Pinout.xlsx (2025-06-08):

1. AS5600 Magnetic Encoder
Pin | Function | Wire Color | Notes
VIN | Power 3.3V | Red | Power supply
GND | Ground | Black | Common ground
SCL | I²C Clock | White | I²C clock line
SDA | I²C Data | Gray | I²C data line
OUT | Analog output signal | Yellow | Angle analog voltage output
DIR | Direction signal | Blue | Digital direction output (optional, if used)
GPO | Mode select | Leave floating | Leave unconnected for default mode
2. Accelerometer (8-pin Board)
Pin | Function | Wire Color | Notes
VIN | Power input (5V) | Red | Use only if powering from 5V
3.3V | Power input/output 3.3V | Orange | Use if powering directly with 3.3V, not VIN
GND | Ground | Black | Common ground
SCL | I²C Clock / SPI Clock | White | Clock line for I²C or SPI
SDA | I²C Data | Gray | Data line for I²C
SDO | I²C Addr select / SPI MISO | Yellow | Sets I²C address or SPI data input
NCS | Mode select (I²C/SPI) | Blue | HIGH for I²C mode, LOW for SPI mode
CSB | SPI Chip Select | Green | SPI chip select signal, not used in I²C
3. Photo Sensor (2-wire)
Pin/Line | Function | Wire Color | Notes
Power | VCC | Red | Positive power supply
Ground | GND | Black | Ground
3. Limit Switch (3-wire)
Wire Color | Function | Notes
Black | Common (COM) | Connected to common terminal
Yellow | Normally Open (NO) | Output when switch is activated
White | Normally Closed (NC) | Output when switch is not activated

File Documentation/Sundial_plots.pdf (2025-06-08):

sundial_plots.py

### 1 import mysql.connector 2 import matplotlib.pyplot as plt 3 import matplotlib.animation as animation 4 import numpy as np 5 from collections import deque

6
7 # === CONFIG ===

### 8 DB_CONFIG = {

9 'host': 'localhost',
10 'user': 'esp_user',
11 'password': 'ESPtesting123!!!', 12 'database': 'esp_user'
13 }
14

### 15 MAX_POINTS = 100 # For LDR history 16 SMOOTHING_DELTA = 0.0 # δ smoothing coefficient, adjust for smoothing

17
18 # === DATA BUFFERS ===

### 19 ldr_left_data = deque(maxlen=MAX_POINTS) 20 ldr_right_data = deque(maxlen=MAX_POINTS) 21 sun_azimuth = [0] # For polar chart 22 gnomon_angle = [0] # Simulated gnomon tilt 23 system_state = ["UNKNOWN"]

24
25 # === DATABASE CONNECTION ===

### 26 def fetch_latest_data(): 27 try: 28 conn = mysql.connector.connect(**DB_CONFIG) 29 cursor = conn.cursor(dictionary=True) 30 cursor.execute(""" 31 SELECT * FROM sun_tracking_data 32 ORDER BY timestamp DESC 33 LIMIT %s

34 """, (MAX_POINTS,))

### 35 rows = cursor.fetchall() 36 cursor.close() 37 conn.close() 38 return rows[::-1] # Return in chronological order 39 except mysql.connector.Error as e: 40 print("DB Error:", e) 41 return []

42
43 # === SMOOTHING FUNCTION ===

### 44 def smooth_series(data, delta): 45 if not data: return [] 46 smoothed = [data[0]] 47 for i in range(1, len(data)): 48 a = smoothed[-1] 49 b = data[i] 50 ab = b - a

### 51 c = b - ab * delta 52 smoothed.append(c) 53 return smoothed

54
55 # === MATPLOTLIB SETUP ===

### 56 fig = plt.figure(figsize=(10, 8))

57
58 # Polar plot: Sun Azimuth

### 59 ax1 = fig.add_subplot(221, polar=True) 60 azimuth_line, = ax1.plot([], [], marker='o') 61 ax1.set_title("Sun Azimuth (North = 0°)")

62
63 # Set custom compass direction labels

### 64 ax1.set_theta_zero_location('N') # 0° at the top

65 | ax1.set_theta_direction(-1) | # Clockwise

### 66 ax1.set_thetagrids(

67 angles=[0, 90, 180, 270],

### 68 labels=['N', 'E', 'S', 'W']

69 )
70
71 # Gnomon tilt polar chart

### 72 ax2 = fig.add_subplot(222, polar=True) 73 gnomon_line, = ax2.plot([], [], marker='o') 74 ax2.set_title("Gnomon Tilt Angle")

75
76 # LDR plot

### 77 ax3 = fig.add_subplot(223) 78 ldr_left_plot, = ax3.plot([], [], label='LDR Left') 79 ldr_right_plot, = ax3.plot([], [], label='LDR Right') 80 ax3.set_title("LDR Sensor Values (Smoothed)") 81 ax3.legend() 82 ax3.set_ylim(0, 5096)

83
84 # System state display

### 85 ax4 = fig.add_subplot(224) 86 ax4.axis('off') 87 state_text = ax4.text(0.5, 0.5, "", fontsize=18, ha='center', va='center')

88
89 # === UPDATE FUNCTION ===

### 90 def update_plot(frame): 91 data = fetch_latest_data() 92 if not data: 93 return

94

### 95 latest = data[-1] 96 sun_azimuth[0] = latest['sun_azimuth'] 97 gnomon_angle[0] = latest['latitude'] # Adjust if needed 98 system_state[0] = latest['system_state']

99
100 ldr_left_raw = [row['ldr_left'] for row in data]
101 ldr_right_raw = [row['ldr_right'] for row in data]
102
103 smoothed_left = smooth_series(ldr_left_raw, SMOOTHING_DELTA)

104 smoothed_right = smooth_series(ldr_right_raw, SMOOTHING_DELTA) 105
106 ldr_left_data.clear()
107 ldr_left_data.extend(smoothed_left)
108 ldr_right_data.clear()
109 ldr_right_data.extend(smoothed_right) 110
111 # Sun azimuth polar update
112 az_rad = np.deg2rad(sun_azimuth[0])
113 azimuth_line.set_data([0, az_rad], [0, 1]) 114
115 # Gnomon tilt polar update
116 gn_rad = np.deg2rad(gnomon_angle[0])
117 gnomon_line.set_data([0, gn_rad], [0, 1]) 118
119 # LDR plot update
120 x_vals = list(range(len(ldr_left_data)))
121 ldr_left_plot.set_data(x_vals, list(ldr_left_data)) 122 ldr_right_plot.set_data(x_vals, list(ldr_right_data)) 123 ax3.set_xlim(0, len(ldr_left_data))
124
125 # System state display
126 state_text.set_text(f"System State:\n{system_state[0]}") 127
128 # === START ANIMATION ===
129 ani = animation.FuncAnimation(fig, update_plot, interval=1000) 130 plt.tight_layout()
131 plt.show()
132

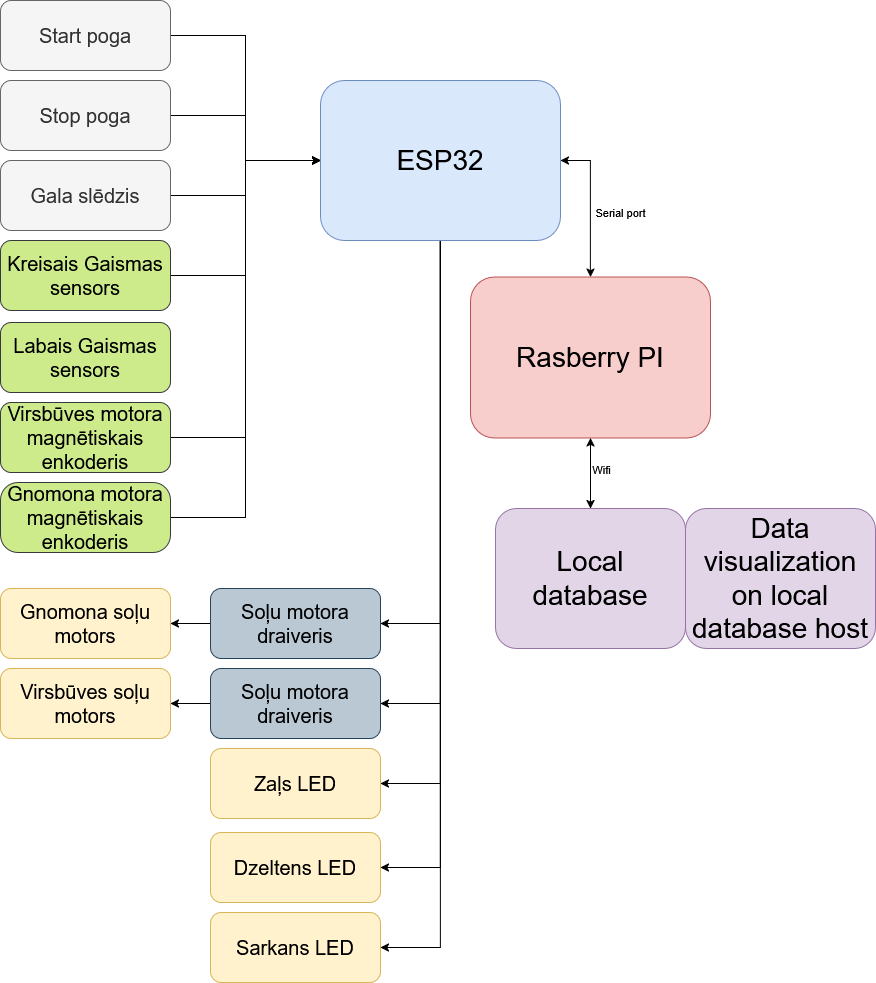
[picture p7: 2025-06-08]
Electronics/SunDialFunc diagram.png

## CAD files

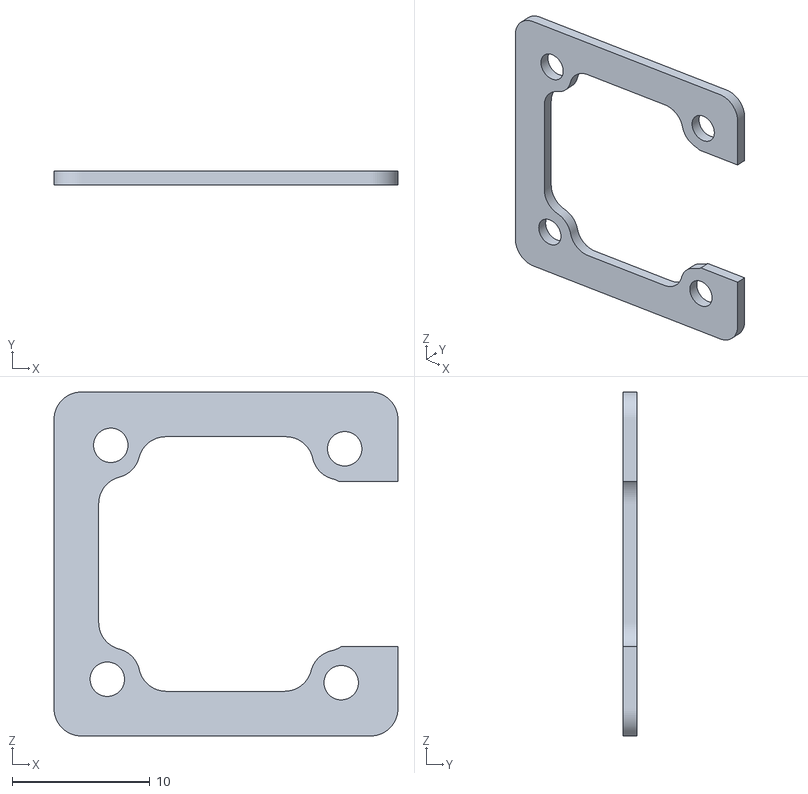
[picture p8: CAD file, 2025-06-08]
CAD/SDL_PL_004_4.stl
25.0 x 1.00 x 25.0

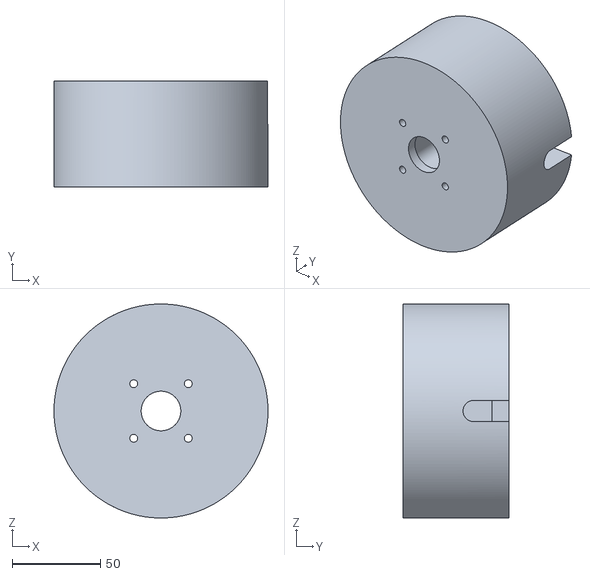
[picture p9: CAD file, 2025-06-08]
CAD/SDL_PL_004_1.stl
121.5 x 60.0 x 121.5

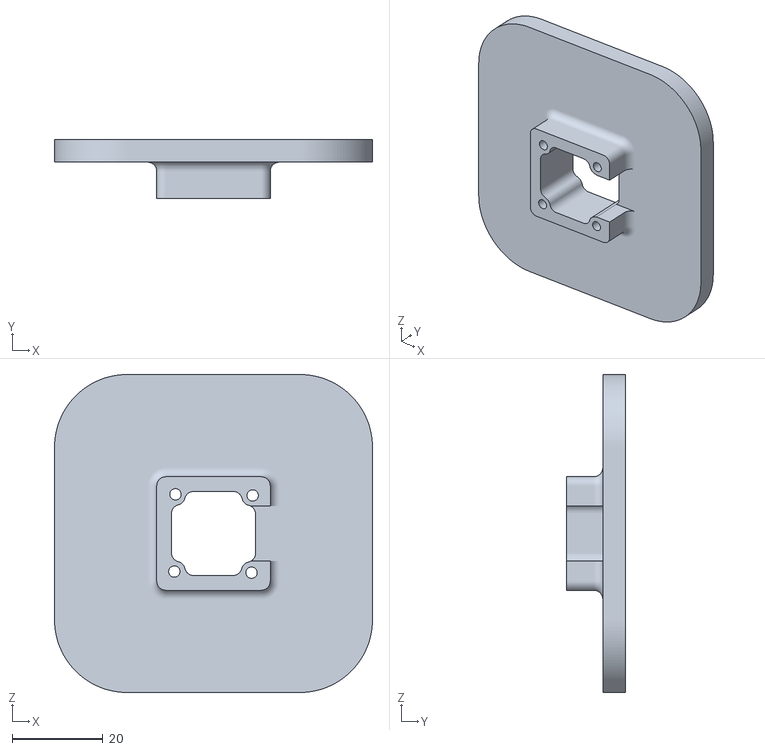
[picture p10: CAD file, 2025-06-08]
CAD/SDL_PL_004_3.stl
70.0 x 13.0 x 70.0

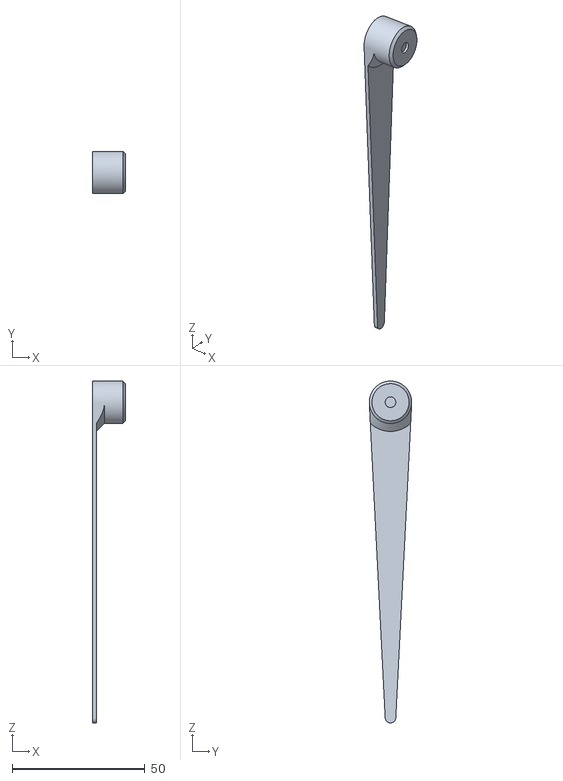
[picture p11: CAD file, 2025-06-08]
CAD/SDL_PL_002.stl
12.5 x 16.0 x 128.9

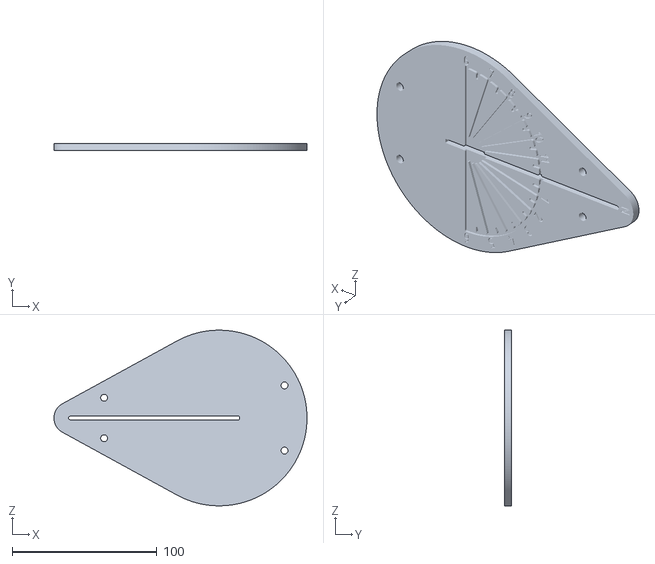
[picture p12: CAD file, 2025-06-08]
CAD/SDL_PL_001.stl
175.0 x 5.00 x 121.5

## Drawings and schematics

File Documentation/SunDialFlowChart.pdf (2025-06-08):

Pamatcilpa | Pogu vadības cilpa

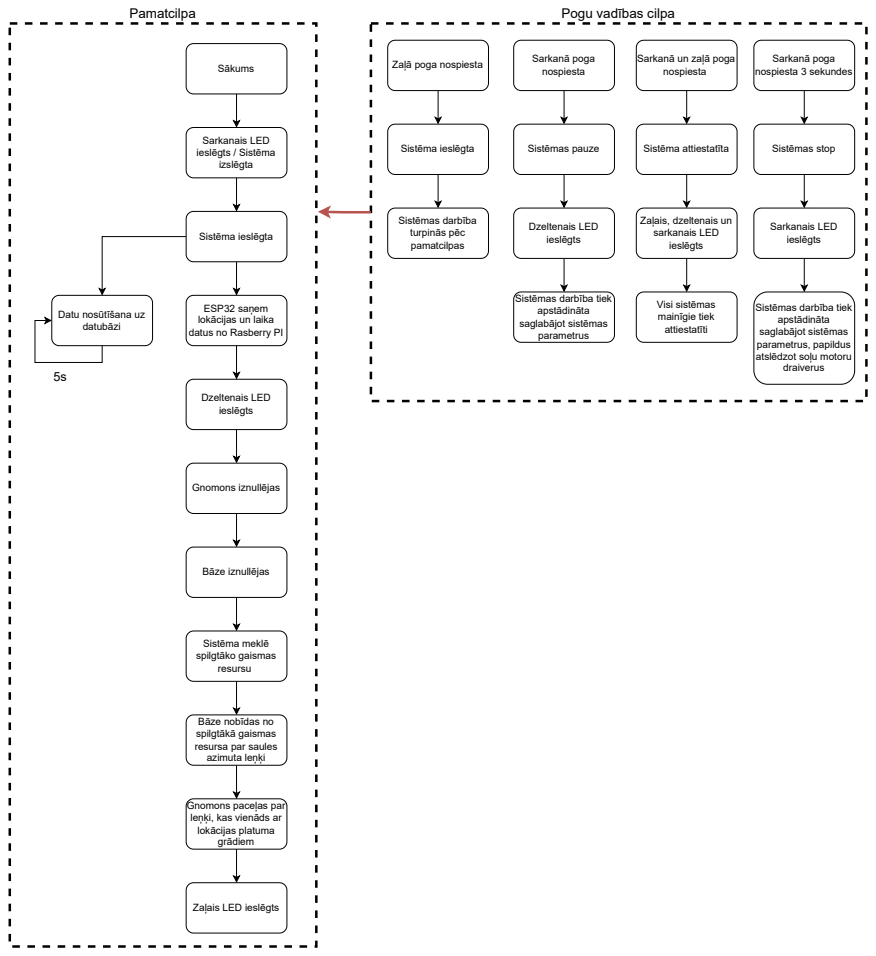
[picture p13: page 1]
Sākums; Sarkanais LED ieslēgts / Sistēma izslēgta; Sistēma ieslēgta; Dzeltenais LED ieslēgts; Gnomons iznullējas; Bāze iznullējas; Sistēma meklē spilgtāko gaismas resursu; Sarkanā poga nospiesta; Sarkanā poga nospiesta 3 sekundes; Sistēmas pauze; Sistēma attiestatīta; Sistēmas stop; Sarkanais LED ieslēgts; Visi sistēmas mainīgie tiek attiestatīti; Sistēmas darbība turpinās pēc pamatcilpas

nospiesta Zaļā poga nospiesta

Sarkanā un zaļā poga

Zaļais, dzeltenais un
sarkanais LED
ieslēgts

Sistēmas darbība tiek
apstādināta
saglabājot sistēmas
parametrus

ESP32 saņem
lokācijas un laika
datus no Rasberry PI

parametrus, papildus
atslēdzot soļu motoru
draiverus

Datu nosūtīšana uz
datubāzi

Bāze nobīdas no
spilgtākā gaismas
resursa par saules
azimuta leņķi

Gnomons paceļas par
leņķi, kas vienāds ar
lokācijas platuma
grādiem

Zaļais LED ieslēgts

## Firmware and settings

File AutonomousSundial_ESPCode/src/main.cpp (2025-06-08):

#include <Arduino.h>
#include <AccelStepper.h>
#include <Bounce2.h>
#include <SolarCalculator.h>
#include <TimeLib.h>

  // === Pin Definitions ===

  // Gnomon motor (Motor 2)
  #define GNOMON_STEP_PIN 27    // DRV8825 STEP (Gnomon motor)
  #define GNOMON_DIR_PIN 32     // DRV8825 DIR (Gnomon motor)
  #define GNOMON_EN_PIN 25      // DRV8825 EN (Gnomon motor)
  AccelStepper gnomonMotor(AccelStepper::DRIVER, GNOMON_STEP_PIN, GNOMON_DIR_PIN);
  int gnomonZeroPosition = 0;

  // Base motor (Motor 1) 
  #define BASE_STEP_PIN 14      // DRV8825 STEP (Base motor)
  #define BASE_DIR_PIN 12       // DRV8825 DIR (Base motor)
  #define BASE_EN_PIN 13        // DRV8825 EN (Base motor)
  AccelStepper baseMotor(AccelStepper::DRIVER, BASE_STEP_PIN, BASE_DIR_PIN);

  // Light Dependent Resistors (LDR)
  #define LDR_RIGHT_PIN 34      // Photocell (LDR) right side
  #define LDR_LEFT_PIN 26       // Photocell (LDR) left side

  // Limit switch
  #define LIMIT_SWITCH_PIN 5    // Limit switch (Normally Open)

  // LEDs
  #define LED_GREEN_PIN 18      // Green LED (anode)
  #define LED_YELLOW_PIN 19     // Yellow LED (anode)
  #define LED_RED_PIN 21        // Red LED (anode)

  // Pushbuttons
  #define BUTTON_GREEN_PIN 4    // Green pushbutton
  #define BUTTON_RED_PIN 2      // Red pushbutton

  Bounce greenButton = Bounce();
  Bounce redButton = Bounce();

  //Sun position values
  double latitude = 56.5047;     // Your latitude
  double longitude = 21.0108;    // Your longitude
  int utc_offset = 3;            // Local time zone offset

  // Set manually:
  int setHour = 5;
  int setMinute = 50;
  int setSecond = 0;
  int setDay = 1;
  int setMonth = 6;
  int setYear = 2025;

  double sunAzimuth = 0.0;
  int azimuthTarget = 0;

  //Serial send delay
  unsigned long lastDataSendTime = 0;
  const unsigned long dataSendInterval = 1000; // send every 1000 ms = 1 second

  //Serial communication data
  bool timeReceived = false;
  bool locationReceived = false;

  //Serial Commands
  /*
  
TIME:12,0,0,1,6,2025
LOC:56.946,24.105
  */

  // System states 
enum SystemState {
  SYSTEM_OFF,
  SYSTEM_ON,
  SYSTEM_PAUSED,
  SYSTEM_RESET
  };

SystemState currentState = SYSTEM_OFF;

//Subsstates
enum SystemSubState {
  STEP_ZERO_GNOMON,
  STEP_ZERO_BASE,
  SUN_TRACKING,
  STEP_ROTATE_BASE,
  STEP_ROTATE_GNOMON,
  STEP_DONE
};

SystemSubState subState = STEP_ZERO_GNOMON;

  // AS5600 Analog Outputs
  #define AS5600_GNOMON_PIN 33  // Gnomon AS5600 analog out
  #define AS5600_BASE_PIN 35    // Base AS5600 analog out
  const int BASE_SENSOR_OFFSET = -120; // Opposite of 2700 on a 12-bit scale

  // Solar positioning values
  int  SunOffsetAmount = round(90 * (4096.0 / 360.0));  // Sun axiom Offset angle
  int  gnomonOffsetAmount = (round(-(latitude-11.77)) * (4096.0 / 360.0));  // Gnomon Offset angle
  int  gnomonZeroTarget = round(-220 * (4096.0 / 360.0));  // Gnomon Zero target angle
  const int baseZeroTarget = 2150;  // or whatever value you consider zero

int readBaseSensorOffset() {
  int raw = analogRead(AS5600_BASE_PIN);
  return (raw + BASE_SENSOR_OFFSET + 4096) % 4096;
}

struct MotorRotationState {
  bool started = false;
  bool complete = false;
  int startingPosition = 0;
};

MotorRotationState baseOffsetState;
MotorRotationState gnomonOffsetState;
MotorRotationState gnomonTargetState;
MotorRotationState baseZeroState;
MotorRotationState baseTrackingState;

void resetMotorStates() {
  baseOffsetState.started = false;
  baseOffsetState.complete = false;

  gnomonOffsetState.started = false;
  gnomonOffsetState.complete = false;

  gnomonTargetState.started = false;
  gnomonTargetState.complete = false;

  baseZeroState.started = false;
  baseZeroState.complete = false;

  baseTrackingState.started = false;
  baseTrackingState.complete = false;
}

bool trackLightSource(AccelStepper &motor, int ldrLeftPin, int ldrRightPin, MotorRotationState &state) {
  const int tolerance = 5;
  const int minBrightness = 2000;
  const float brightnessThresholdRatio = 0.8;
  static int maxBrightnessSeen = 0;
  static unsigned long lastMaxUpdate = 0;

  if (state.complete) return true;

  if (!state.started) {
    motor.setMaxSpeed(200);
    state.started = true;
    Serial.println("Light tracking started...");
  }

  int leftValue = analogRead(ldrLeftPin);
  int rightValue = analogRead(ldrRightPin);
  int maxCurrent = (leftValue + rightValue)/2;

  // Update peak brightness
  if (millis() - lastMaxUpdate > 60000 || maxCurrent > maxBrightnessSeen) {
    maxBrightnessSeen = maxCurrent;
    lastMaxUpdate = millis();
  }

  int brightnessThreshold = brightnessThresholdRatio * maxBrightnessSeen;

  Serial.print("LDR Left: ");
  Serial.print(leftValue);
  Serial.print(" | LDR Right: ");
  Serial.print(rightValue);
  Serial.print(" | Max seen: ");
  Serial.print(maxBrightnessSeen);
  Serial.print(" | Required: ");
  Serial.println(brightnessThreshold);

  int difference = leftValue - rightValue;

  // Check if aligned and bright enough
  if (
    abs(difference) <= tolerance &&
    leftValue >= minBrightness &&
    rightValue >= minBrightness &&
    maxCurrent >= brightnessThreshold
  ) {
    motor.stop();
    state.complete = true;
    delay(2000);
    Serial.println("Light tracking complete.");
    return true;
  }

  // Keep moving toward brighter side
  motor.setSpeed(difference > 0 ? -50 : 50);
  motor.runSpeed();
  return false;
}

bool rotateMotorByOffset(AccelStepper &motor, int sensorPin,int offsetAngle, MotorRotationState &state, int maxSpeed = 200, int moveSpeed = 100, int tolerance = 2) {
  if (state.complete) return true;

  if (!state.started) {
    motor.setMaxSpeed(maxSpeed);
    state.startingPosition = analogRead(sensorPin);
    state.started = true;

    Serial.print("Starting position: ");
    Serial.println(state.startingPosition);
    Serial.println("Rotating motor by offset...");
  }

  int currentPosition = analogRead(sensorPin);
  int targetPosition = (state.startingPosition + offsetAngle + 4096) % 4096;

  int difference = (targetPosition - currentPosition + 4096) % 4096;
  if (difference > 2048) difference -= 4096;

  Serial.print("Current: ");
  Serial.print(currentPosition);
  Serial.print(" | Target: ");
  Serial.print(targetPosition);
  Serial.print(" | Diff: ");
  Serial.println(difference);

  if (abs(difference) <= tolerance) {
    motor.stop();
    state.complete = true;
    Serial.println("Offset rotation complete.");
    return true;
  }

  motor.setSpeed(difference > 0 ? -moveSpeed : moveSpeed);
  motor.runSpeed();
  return false;
}

bool rotateMotorToPosition(AccelStepper &motor, int sensorPin, int targetPosition, MotorRotationState &state) {
  const int tolerance = 2;

  if (state.complete) return true;

  if (!state.started) {
    motor.setMaxSpeed(200);
    state.started = true;
    Serial.print("Target Position: ");
    Serial.println(targetPosition);
  }

  int currentPosition = analogRead(sensorPin);
  int difference = (targetPosition - currentPosition + 4096) % 4096;
  if (difference > 2048) difference -= 4096;

  Serial.print("Current: ");
  Serial.print(currentPosition);
  Serial.print(" | Target: ");
  Serial.print(targetPosition);
  Serial.print(" | Diff: ");
  Serial.println(difference);

  if (abs(difference) <= tolerance) {
    motor.stop();
    state.complete = true;
    Serial.println("Motor reached target position.");
    return true;
  }

  motor.setSpeed(difference > 0 ? -100 : 100);
  motor.runSpeed();
  return false;
}

void checkButtons() {
  greenButton.update();
  redButton.update();

  static unsigned long redPressStart = 0;
  static bool redHoldChecked = false;

  bool greenPressed = greenButton.read() == HIGH;
  bool redPressed = redButton.read() == HIGH;

  // Handle both buttons for system reset
if (greenPressed && redPressed) {
    currentState = SYSTEM_RESET;
    Serial.println("System RESET");
    digitalWrite(LED_GREEN_PIN, HIGH);
    digitalWrite(LED_YELLOW_PIN, HIGH);
    digitalWrite(LED_RED_PIN, HIGH);
    return;
  }

  // Green button press
  if (greenButton.rose() && !redPressed) {
    currentState = SYSTEM_ON;
    Serial.println("System ON");
  }

  // Red button press
  if (redButton.rose()) {
    currentState = SYSTEM_PAUSED;
    redPressStart = millis();
    redHoldChecked = false;
    Serial.println("System PAUSED");    
  }

  // Check if red has been held for 3 seconds
  if (redPressed && currentState == SYSTEM_PAUSED && !redHoldChecked) {
    if (millis() - redPressStart >= 3000) {
      currentState = SYSTEM_OFF;
      redHoldChecked = true;
      Serial.println("System OFF (long hold)");
    }
  }

  // Reset the flag if red is released
  if (redButton.rose()) {
    redHoldChecked = false;
  }
}

void calculateSunAzimuth() {
  // Set system time
  setTime(setHour, setMinute, setSecond, setDay, setMonth, setYear);
  time_t utc = now();

  double elevation;
  calcHorizontalCoordinates(utc, (round(-(latitude-11.77)) * (4096.0 / 360.0)), longitude, sunAzimuth, elevation);

  Serial.print("Sun Azimuth: ");
  Serial.print(sunAzimuth);
  Serial.println("°");

  // Convert to sensor units (0–4096)
  azimuthTarget = round((sunAzimuth / 360.0) * 4096.0);
  Serial.print("Sensor units: ");
  Serial.println(azimuthTarget);
}

void parseSerialCommand(const String& input) {
  if (input.startsWith("TIME:")) {
    sscanf(input.c_str(), "TIME:%d,%d,%d,%d,%d,%d",
           &setHour, &setMinute, &setSecond, &setDay, &setMonth, &setYear);

    timeReceived = true;
    Serial.println("Time variables updated.");
  } 
  else if (input.startsWith("LOC:")) {
    sscanf(input.c_str(), "LOC:%lf,%lf", &latitude, &longitude);
    locationReceived = true;
    Serial.println("Location variables updated.");
  } 
  else {
    Serial.println("Unknown command.");
  }
}

void receiveSerialData() {
  static String inputBuffer = "";

  while (Serial.available()) {
    char c = Serial.read();

    if (c == '\n') {
      // Process complete input line
      parseSerialCommand(inputBuffer);
      inputBuffer = "";
    } else {
      inputBuffer += c;
    }
  }
}

void sendSystemData() {
  // Get current time from TimeLib
  char nowTimestamp[20];
  snprintf(nowTimestamp, sizeof(nowTimestamp), "%04d-%02d-%02d %02d:%02d:%02d",
           year(), month(), day(), hour(), minute(), second());

  time_t utc = now();
  double elevation;       
  calcHorizontalCoordinates(utc, round(-(latitude-11.77) * (4096.0 / 360.0)), longitude, sunAzimuth, elevation);         

  // Begin with identifiable prefix
  Serial.print("DATA:");

  // Send CSV-formatted line over Serial
  Serial.print(nowTimestamp); Serial.print(",");
  Serial.print(latitude); Serial.print(",");
  Serial.print(longitude); Serial.print(",");
  Serial.print(sunAzimuth); Serial.print(",");
  Serial.print(analogRead(LDR_LEFT_PIN)); Serial.print(",");
  Serial.print(analogRead(LDR_RIGHT_PIN)); Serial.print(",");
  Serial.print(readBaseSensorOffset()); Serial.print(",");

  // Send system state as a string
  switch (currentState) {
    case SYSTEM_OFF:    Serial.println("SYSTEM_OFF"); break;
    case SYSTEM_ON:     Serial.println("SYSTEM_ON"); break;
    case SYSTEM_PAUSED: Serial.println("SYSTEM_PAUSED"); break;
    case SYSTEM_RESET:  Serial.println("SYSTEM_RESET"); break;
  }
}

// === Setup ===
void setup() {
  Serial.begin(115200);

  // Initialize LED pins
  pinMode(LED_GREEN_PIN, OUTPUT);
  pinMode(LED_YELLOW_PIN, OUTPUT);
  pinMode(LED_RED_PIN, OUTPUT);

  // Example: Turn all LEDs off at startup
  digitalWrite(LED_GREEN_PIN, LOW);
  digitalWrite(LED_YELLOW_PIN, LOW);
  digitalWrite(LED_RED_PIN, LOW);

  pinMode(GNOMON_EN_PIN, OUTPUT);
  pinMode(BASE_EN_PIN, OUTPUT);

  //Attach buttons
  greenButton.attach(BUTTON_GREEN_PIN, INPUT);
  redButton.attach(BUTTON_RED_PIN, INPUT);

  // Set debounce interval
  greenButton.interval(10);  // or whatever fits your physical setup
  redButton.interval(10);
  Serial.println("System OFF");         

}

// === Loop ===
void loop() {
  checkButtons();
  switch (currentState) {
    case SYSTEM_OFF:
      digitalWrite(GNOMON_EN_PIN, HIGH);  // Enable gnomon driver
      digitalWrite(BASE_EN_PIN, HIGH);    // Enable base driver
      digitalWrite(LED_GREEN_PIN, LOW);
      digitalWrite(LED_YELLOW_PIN, LOW);
      digitalWrite(LED_RED_PIN, HIGH);
      break;

    case SYSTEM_ON:
      if (!timeReceived || !locationReceived) {
          receiveSerialData();
          Serial.println("Waiting for TIME and LOCATION data...");
          delay(1000);
          break;
      }
      digitalWrite(GNOMON_EN_PIN, LOW);  // Enable gnomon driver
      digitalWrite(BASE_EN_PIN, LOW);    // Enable base driver
      switch (subState) {
        case STEP_ZERO_GNOMON:

          digitalWrite(LED_GREEN_PIN, LOW);
          digitalWrite(LED_YELLOW_PIN, HIGH);
          digitalWrite(LED_RED_PIN, LOW);
          rotateMotorByOffset(gnomonMotor, AS5600_GNOMON_PIN, gnomonZeroTarget, gnomonTargetState);
          if ((digitalRead(LIMIT_SWITCH_PIN) == HIGH)) {
            calculateSunAzimuth();
            subState = STEP_ZERO_BASE;
          }
          break;

        case STEP_ZERO_BASE:
          digitalWrite(LED_GREEN_PIN, LOW);
          digitalWrite(LED_YELLOW_PIN, HIGH);
          digitalWrite(LED_RED_PIN, LOW);
          if (rotateMotorToPosition(baseMotor, AS5600_BASE_PIN, baseZeroTarget, baseZeroState)) {
            delay(1000);
            subState = SUN_TRACKING;
          }
          break;

        case SUN_TRACKING:
          digitalWrite(LED_GREEN_PIN, LOW);
          digitalWrite(LED_YELLOW_PIN, HIGH);
          digitalWrite(LED_RED_PIN, LOW);
          if (trackLightSource(baseMotor, LDR_LEFT_PIN, LDR_RIGHT_PIN, baseTrackingState)) {
            subState = STEP_ROTATE_BASE;  // Or whatever comes next
          }
        break;

        case STEP_ROTATE_BASE:
          digitalWrite(LED_GREEN_PIN, LOW);
          digitalWrite(LED_YELLOW_PIN, HIGH);
          digitalWrite(LED_RED_PIN, LOW);
          if (rotateMotorByOffset(baseMotor, AS5600_BASE_PIN, azimuthTarget, baseOffsetState)) {
            subState = STEP_ROTATE_GNOMON;
          }
          break;

        case STEP_ROTATE_GNOMON:
          digitalWrite(LED_GREEN_PIN, LOW);
          digitalWrite(LED_YELLOW_PIN, HIGH);
          digitalWrite(LED_RED_PIN, LOW);
          if (rotateMotorByOffset(gnomonMotor, AS5600_GNOMON_PIN, gnomonOffsetAmount, gnomonOffsetState)) {
            subState = STEP_DONE;
          }
          break;

        case STEP_DONE:
          // System is now fully set up
          digitalWrite(LED_GREEN_PIN, HIGH);
          digitalWrite(LED_YELLOW_PIN, LOW);
          digitalWrite(LED_RED_PIN, LOW);
          Serial.println("All system tasks complete.");
          break;
      }
      break;

    case SYSTEM_PAUSED:
      digitalWrite(LED_GREEN_PIN, LOW);
      digitalWrite(LED_YELLOW_PIN, HIGH);
      digitalWrite(LED_RED_PIN, LOW);
      break;

    case SYSTEM_RESET:
      // Reset everything
      resetMotorStates();
      timeReceived = false;
      locationReceived = false;
      subState = STEP_ZERO_GNOMON;
      break;
  }
  if (millis() - lastDataSendTime >= dataSendInterval) {
      lastDataSendTime = millis();
      sendSystemData();
  }
}

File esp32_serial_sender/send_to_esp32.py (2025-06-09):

import mysql.connector
import serial
import time
import geocoder
from datetime import datetime, timedelta

# Serial connection
ser = serial.Serial('COM6', 115200, timeout=1)
time.sleep(2)  # Wait for ESP32 to initialize

# MySQL connection setup
db = mysql.connector.connect(
    host="localhost",
    user="database_USER",
    password="database_PW",
    database="database_Name"
)
cursor = db.cursor()

def send_time_and_location():
    offset = timedelta(hours=3)
    now = datetime.utcnow() + offset
    time_string = f"TIME:{now.hour},{now.minute},{now.second},{now.day},{now.month},{now.year}\n"

    g = geocoder.ip('me')
    if g.ok and g.latlng:
        latitude, longitude = g.latlng
    else:
        latitude, longitude = 37.2350, -115.8111  # Fallback if geolocation fails
        print("⚠️  Using fallback coordinates.")

    location_string = f"LOC:{latitude},{longitude}\n"

    print("Sending to ESP32:")
    print("  Time:", time_string.strip())
    print("  Location:", location_string.strip())

    ser.write(time_string.encode())
    time.sleep(0.1)
    ser.write(location_string.encode())

    print("  Status: Sent\n")

def insert_data_to_mysql(timestamp, latitude, longitude, azimuth, ldr_left, ldr_right, base_pos, state):
    query = """
        INSERT INTO sun_tracking_data (
            timestamp, latitude, longitude, sun_azimuth,
            ldr_left, ldr_right, base_position, system_state
        ) VALUES (%s, %s, %s, %s, %s, %s, %s, %s)
    """
    values = (timestamp, latitude, longitude, azimuth, ldr_left, ldr_right, base_pos, state)
    cursor.execute(query, values)
    db.commit()

def read_esp_data():
    while ser.in_waiting:
        line = ser.readline().decode().strip()
        if line.startswith("DATA:"):
            data = line[len("DATA:"):]
            print("[ESP DATA]", data)
            parts = data.split(',')
            if len(parts) == 8:
                timestamp, lat, lon, az, ldr_l, ldr_r, base, state = parts
                try:
                    insert_data_to_mysql(timestamp, float(lat), float(lon), float(az),
                                         int(ldr_l), int(ldr_r), int(base), state)
                except Exception as e:
                    print("Error inserting to DB:", e)

# === Main loop ===
last_sent = time.time()

while True:
    now = time.time()

    # Send time/location update every 5 seconds
    if now - last_sent >= 5:
        send_time_and_location()
        last_sent = now

    # Always listen for ESP responses
    read_esp_data()

    time.sleep(0.9)
